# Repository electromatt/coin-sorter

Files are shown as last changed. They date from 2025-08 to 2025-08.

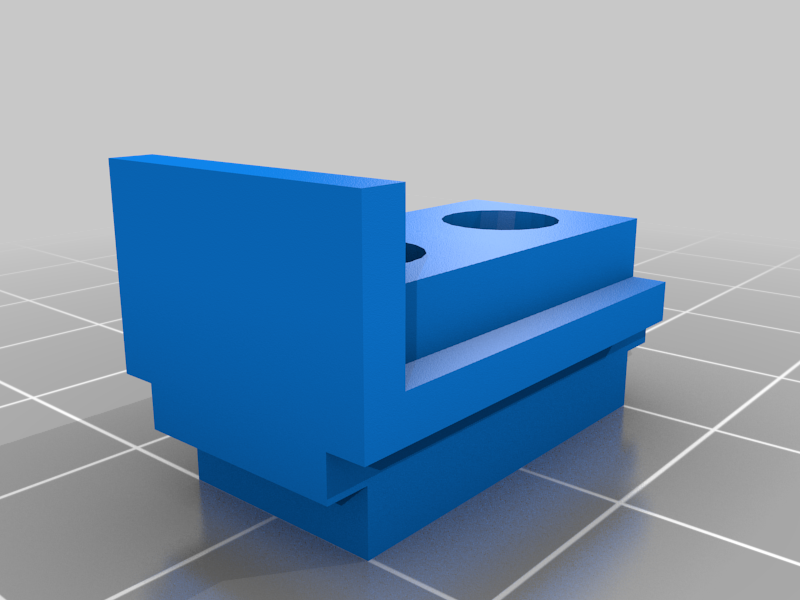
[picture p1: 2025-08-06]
models/images/Q-QuarterSensor.png

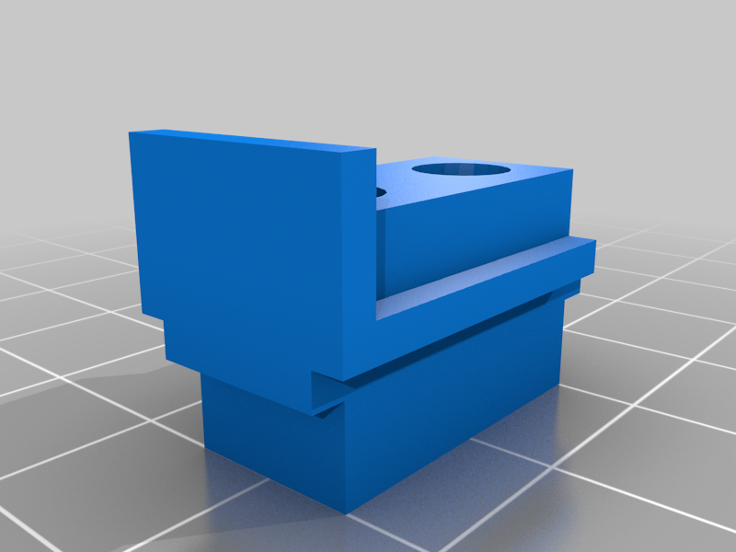
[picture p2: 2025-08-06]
models/images/T-NickelSensor.png

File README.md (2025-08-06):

# Coin Sorter with LED Matrix Display

A sophisticated coin sorting and counting system with real-time LED matrix display, motor control, and firework animations. This project automatically detects and counts US coins (pennies, nickels, dimes, quarters) while providing visual feedback through a 32x5 LED matrix display.

## Features

### 🪙 Coin Detection
- **4 Independent Sensors**: Separate analog sensors for each coin type
- **Real-time Detection**: Instant coin recognition with visual feedback
- **No Missed Coins**: Optimized detection algorithm ensures every coin is counted
- **Non-blocking Operation**: Coin detection never blocks other system functions

### 💰 Display System
- **32x5 LED Matrix**: High-resolution display showing dollar amounts
- **Money Format**: Displays totals in XX.XX format (e.g., $12.34)
- **Color-coded Feedback**: Different colors for different operations
- **Non-blocking Animations**: Firework celebrations for milestones

### ⚙️ Motor Control
- **Pulsing Operation**: Motor runs in controlled pulses for precise movement
- **Bidirectional Control**: Forward and backward sequences
- **Configurable Sequences**: Adjustable pulse timing and direction changes
- **H-bridge Control**: Full forward/backward control with PWM speed control

### 🎮 User Controls
- **Dollar Adjustment**: Add/subtract $1.00 with dedicated buttons
- **Motor Control**: Manual motor activation button
- **Reset Function**: Clear total amount (currently disabled to prevent blocking)
- **Debug Mode**: Comprehensive logging and sensor monitoring

### 💾 Data Persistence
- **EEPROM Storage**: Total amount persists across power cycles
- **Data Integrity**: Magic number verification ensures valid saved data
- **Automatic Loading**: System loads previous total on startup

## Hardware Requirements

### Core Components
- **Arduino Uno** (or compatible board)
- **32x5 LED Matrix** (160 NeoPixels)
- **4x Analog Sensors** (for coin detection)
- **DC Motor** with H-bridge driver
- **3x Push Buttons** (dollar add/subtract, motor control)

### Pin Configuration
```
LED Matrix: Pin 7
Penny Sensor: A2
Nickel Sensor: A1  
Dime Sensor: A3
Quarter Sensor: A0
Reset Button: Pin 6
Add Dollar: Pin 2
Subtract Dollar: Pin 3
Motor Forward: Pin 9
Motor Backward: Pin 10
Motor Button: Pin 8
Motor Enable: Pin 11 (PWM)
```

## Installation & Setup

### 1. Hardware Assembly
1. Connect the LED matrix to pin 7
2. Wire each coin sensor to its designated analog pin
3. Connect motor driver to pins 9, 10, 11 (H-bridge configuration)
4. Wire push buttons to their respective pins
5. Ensure proper power supply for motor and sensors

### 2. Software Setup
1. Install required libraries:
   ```bash
   # Arduino IDE Library Manager
   Adafruit NeoPixel
   ```
2. Upload `coin_sorter.ino` to your Arduino
3. Open Serial Monitor (9600 baud) for debug output

### 3. Configuration
Adjust these settings in the code as needed:
```cpp
#define DEBUG_MODE 1                    // Enable debug output
#define DEBOUNCE_DELAY 10              // Coin detection debounce (ms)
#define DISPLAY_DELAY 25               // Display update frequency (ms)
#define COIN_THRESHOLD 640             // Analog threshold for coin detection
#define FIREWORK_INTERVAL 1000         // Firework every $10.00 (1000 cents)
```

## Usage

### Basic Operation
1. **Power On**: System initializes and loads previous total from EEPROM
2. **Insert Coins**: Drop coins into the sorter - they're automatically detected and counted
3. **View Total**: Current total displays in real-time on LED matrix
4. **Celebrations**: Firework animations trigger at $10.00 milestones

### Button Functions
- **Add Dollar (+$1.00)**: Cyan flash, adds $1.00 to total
- **Subtract Dollar (-$1.00)**: Orange flash, subtracts $1.00 (prevents negative)
- **Motor Control**: Activates motor pulsing sequence
- **Reset**: Clears total (currently disabled to prevent blocking)

### Debug Features
When `DEBUG_MODE` is enabled:
- Real-time sensor value monitoring
- Coin detection logging with sensor values
- Motor operation status and sequence tracking
- EEPROM save/load confirmation

## Technical Details

### Coin Detection Algorithm
```cpp
// Threshold-based detection with debouncing
bool coinDetected = (analogValue <= COIN_THRESHOLD);

// Non-blocking state machine
if (coinDetected && !lastState && timeSinceLastDetection > debounceDelay) {
    // Register coin detection
    return coinValue;
}
```

### Motor Control System
- **Pulse Timing**: 100ms on, 100ms off
- **Sequence Pattern**: 4 forward pulses, 1 backward pulse per sequence
- **Total Sequences**: 2 complete sequences per activation
- **H-bridge Control**: Pin 9 (forward), Pin 10 (backward), Pin 11 (PWM enable)
- **Direction Logic**: Forward = Pin 9 HIGH, Pin 10 LOW; Backward = Pin 9 LOW, Pin 10 HIGH

### Display System
- **Resolution**: 32x5 pixels (160 total)
- **Format**: XX.XX dollar display
- **Colors**: Green (normal), Yellow (coin added), Red (error), Cyan (add dollar), Orange (subtract dollar)
- **Animation**: Non-blocking firework effects with multiple bursts

### Memory Management
- **EEPROM Storage**: Persistent total amount across power cycles
- **Magic Number**: Data integrity verification (0xAA55)
- **Automatic Loading**: System loads saved total on startup
- **Error Handling**: Graceful fallback to $0.00 if EEPROM data is invalid

## Code Organization

### Well-Documented Structure
The code includes comprehensive comments explaining:
- **Pin Functions**: What each pin controls and how
- **Configuration Values**: What each constant controls and units
- **Variable States**: Boolean logic and state machine explanations
- **Function Purpose**: What each function does and why
- **Complex Logic**: Motor control algorithms and animation systems

### Key Sections
```cpp
// Pin Definitions with clear explanations
#define MOTOR_FORWARD_PIN 9   // High to drive forward
#define MOTOR_BACKWARD_PIN 10 // High to drive backward
#define MOTOR_ENA_PIN 11      // PWM pin for motor speed control

// Configuration with units and purpose
#define DEBOUNCE_DELAY 10     // Milliseconds for button/coin debouncing
#define COIN_THRESHOLD 640    // Analog threshold for coin detection

// Variable explanations
bool motorDirection = true;    // true = forward, false = backward
bool pulseState = false;      // true = motor on, false = motor off
```

## Troubleshooting

### Common Issues

**Coins Not Detected:**
- Check sensor wiring and connections
- Verify analog pin assignments (A0-A3)
- Test sensor values in debug mode
- Adjust `COIN_THRESHOLD` if needed (default: 640)

**Motor Not Running:**
- Verify H-bridge connections (pins 9, 10, 11)
- Check power supply for motor
- Test motor pins with simple on/off code
- Ensure proper H-bridge configuration

**Display Issues:**
- Verify LED matrix connections to pin 7
- Check power supply for NeoPixels
- Test individual LED segments
- Verify 32x5 matrix configuration

**EEPROM Issues:**
- Check if total persists across power cycles
- Verify magic number in EEPROM
- Test EEPROM read/write functions
- Check for memory corruption

**False Coin Detections:**
- Check for electrical interference
- Adjust debounce timing (`DEBOUNCE_DELAY`)
- Verify sensor mounting and alignment
- Test individual sensor isolation

### Debug Commands
```cpp
// Enable comprehensive debug output
#define DEBUG_MODE 1

// Monitor sensor values in real-time
// Debug output shows: sensor index, analog value, coin value

// Motor operation tracking
// Debug shows: pulse count, sequence progress, direction changes
```

## Customization

### Adjusting Coin Detection
```cpp
// Modify detection threshold
#define COIN_THRESHOLD 640  // Adjust based on sensor calibration

// Change debounce timing
#define DEBOUNCE_DELAY 10   // Milliseconds
```

### Motor Configuration
```cpp
// Adjust pulse timing
#define PULSE_ON_TIME 100   // Milliseconds motor stays on
#define PULSE_OFF_TIME 100  // Milliseconds motor stays off

// Modify sequence pattern
#define FORWARD_PULSES 4    // Number of forward pulses per sequence
#define BACKWARD_PULSES 1   // Number of backward pulses per sequence
#define TOTAL_SEQUENCES 2   // Number of complete sequences to run
```

### Display Customization
```cpp
// Change LED brightness
strip.setBrightness(50);  // 0-255

// Modify firework frequency
#define FIREWORK_INTERVAL 1000  // Every $10.00 (1000 cents)
```

### EEPROM Configuration
```cpp
// Change EEPROM storage address
#define EEPROM_TOTAL_ADDRESS 0  // Address to store total amount

// Modify magic number for data validation
#define EEPROM_MAGIC_NUMBER 0xAA55  // Magic number to verify data is valid
```

## Safety & Maintenance

### Electrical Safety
- Use appropriate power supplies for motor and sensors
- Ensure proper grounding
- Add capacitors for motor noise suppression
- Use separate power for sensitive analog circuits

### Mechanical Maintenance
- Clean coin sensors regularly
- Lubricate motor components as needed
- Check for coin jams in sorting mechanism
- Inspect wiring connections periodically

### Software Updates
- Backup EEPROM data before updates
- Test new configurations thoroughly
- Monitor sensor values after changes
- Verify motor operation with new settings

## Recent Updates

### Code Improvements (Latest)
- **Restored Comprehensive Comments**: All pin functions, configuration values, and complex logic are now well-documented
- **EEPROM Loading on Startup**: System automatically loads previous total when powered on
- **Improved Code Organization**: Better structured with logical grouping of constants and variables
- **Enhanced Debug Output**: More detailed logging for troubleshooting
- **Non-blocking Operation**: All functions designed to prevent blocking coin detection

### Key Changes
- Added `loadTotalFromEEPROM()` call in `setup()` for automatic data restoration
- Restored detailed comments for all pin definitions and configuration values
- Improved variable documentation explaining state machines and boolean logic
- Enhanced motor control comments explaining H-bridge operation
- Better function documentation explaining purpose and behavior

## License

This project is open source. Feel free to modify and distribute according to your needs.

## Contributing

Contributions are welcome! Please:
1. Test thoroughly before submitting
2. Document any hardware changes
3. Include debug output for issues
4. Follow existing code style and comment standards

## Support

For issues or questions:
1. Check the troubleshooting section
2. Enable debug mode for detailed logging
3. Verify hardware connections
4. Test individual components
5. Check EEPROM data integrity

---

**Happy Coin Sorting! 🪙💰**

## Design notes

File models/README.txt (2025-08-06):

US Coin Sorter/Counter - Arduino by rleddington on Thingiverse: https://www.thingiverse.com/thing:5257512

Summary:
Fun coin sorting project for electronics enthusiasts.  This is a remix of "US Coin Sorter Variant" by pjm237, which was itself a remix of "COINSORTER" by neoprenox which I believe is for the Euro coins.  If you're only interested in the coin sorting functionality, I highly recommend pjm237's awesome project!  It works amazingly well.  This version is for US coins only and has been modified to fit a series of IR sensors, and Arduino UNO, and a 16x2 LCD Display to show the total value as well as the coin counts for each denomination.It requires an Arduino UNO and several electronics components and some skill with a soldering iron.  I'm working on a video which I'll link here on how to build and program it.  I also have several left-over components for the projects since amazon requires you to buy multiple of each component.  Let me know if you're interested in a 'kit' for the electronics parts minus the Arduino.Here are links to many of the part's you'll need to complete this project:On/Off Switchhttps://www.amazon.com/gp/product/B08R5PLDBP/ref=ppx_yo_dt_b_asin_title_o03_s00?ie=UTF8&amp;th=1Reset Buttonhttps://www.amazon.com/gp/product/B08JHSG717/ref=ppx_yo_dt_b_asin_title_o03_s00?ie=UTF8&amp;psc=1Battery Connector (9v)https://www.amazon.com/gp/product/B08SL9X2YC/ref=ppx_yo_dt_b_asin_title_o02_s00?ie=UTF8&amp;psc=1Perf Boardhttps://www.amazon.com/Prototyping-Circuit-Breadboards-Envistia-Mall/dp/B07RC68D5C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 Emitter Detectorhttps://www.amazon.com/dp/B07VK3PGR9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 Uno R3https://www.amazon.com/gp/product/B01EWOE0UU/ref=ppx_yo_dt_b_asin_title_o03_s00?ie=UTF8&amp;psc=1Jumper Wireshttps://www.amazon.com/Elegoo-EL-CP-004-Multicolored-Breadboard-arduino/dp/B01EV70C78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 Display Modulehttps://www.amazon.com/gp/product/B07S7PJYM6/ref=ppx_yo_dt_b_asin_title_o03_s02?ie=UTF8&amp;psc=1Wirewrap Wirehttps://www.amazon.com/gp/product/B01LWI20M0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 Bolts/Nuts &amp; Washershttps://www.amazon.com/gp/product/B08125LTBT/ref=ppx_yo_dt_b_search_asin_title?ie=UTF8&amp;psc=1

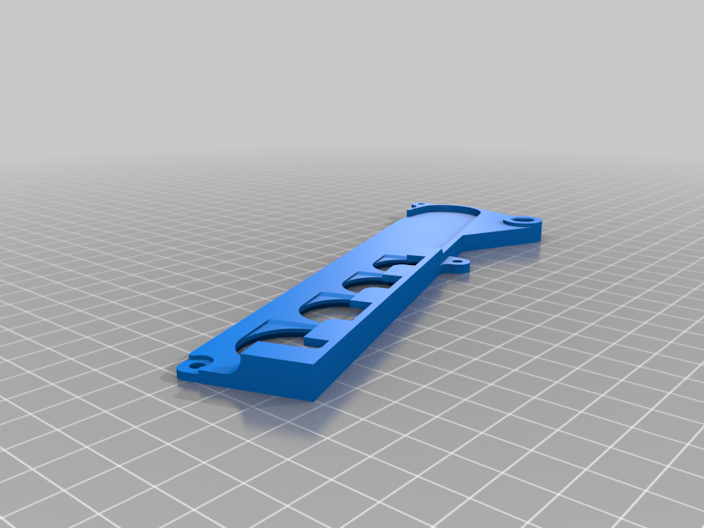
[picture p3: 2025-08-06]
models/images/B-Separator.png

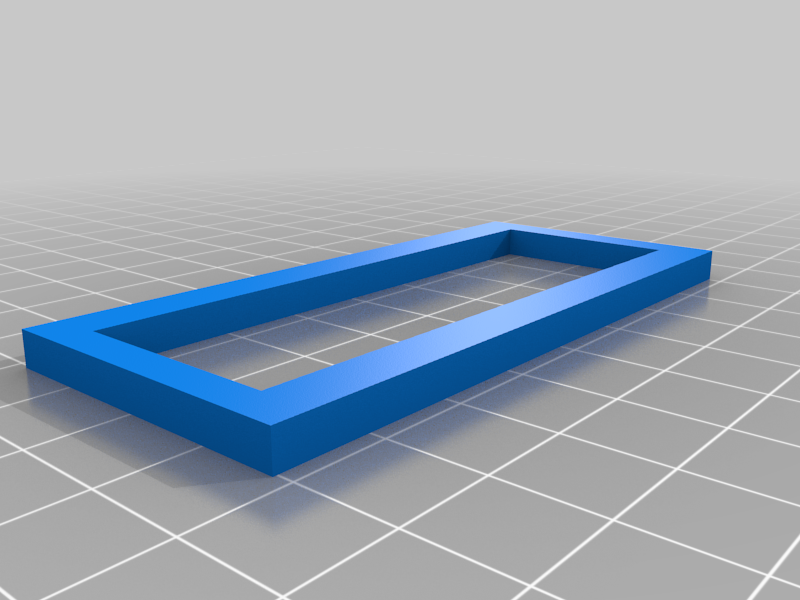
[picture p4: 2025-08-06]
models/images/O-FacePlate.png

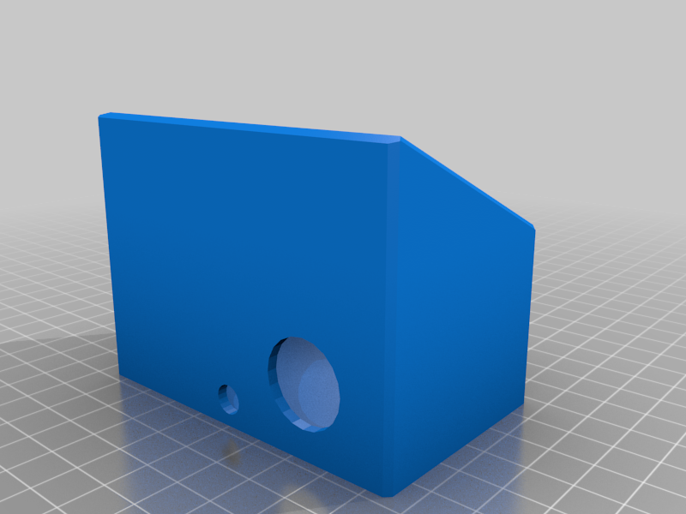
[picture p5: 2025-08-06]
models/images/N-DisplayCase.png

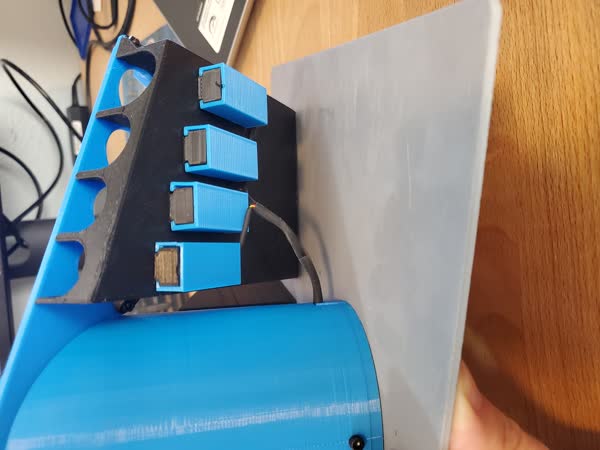
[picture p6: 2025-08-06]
models/images/f088567a-85c6-4a23-a1e6-7ee276b56d47.jpg

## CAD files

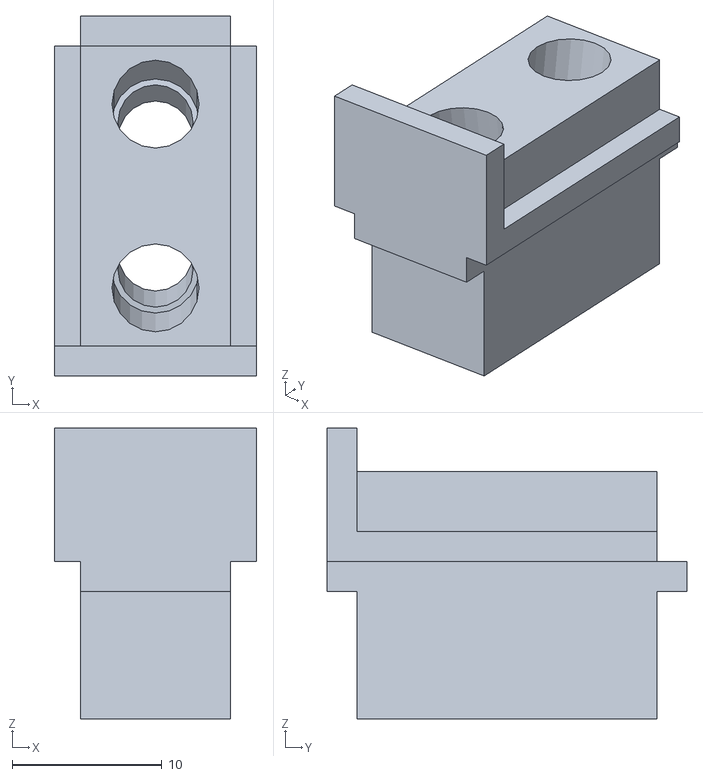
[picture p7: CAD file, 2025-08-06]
models/files/R-DimeSensor.stl
13.5 x 24.0 x 19.4

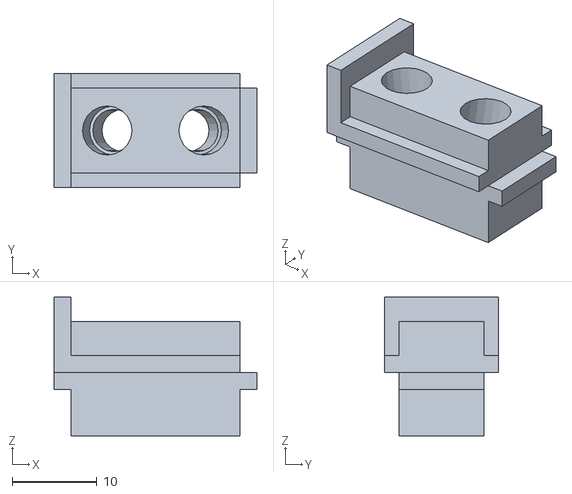
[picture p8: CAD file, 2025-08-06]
models/files/T-NickelSensor.stl
24.0 x 13.5 x 16.4

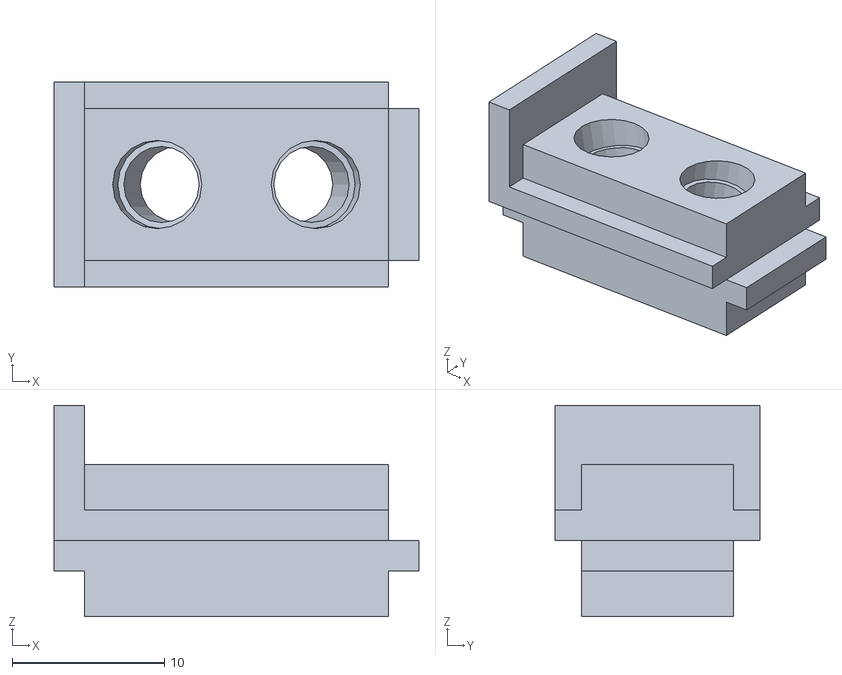
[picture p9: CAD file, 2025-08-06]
models/files/Q-QuarterSensor.stl
24.0 x 13.5 x 13.9

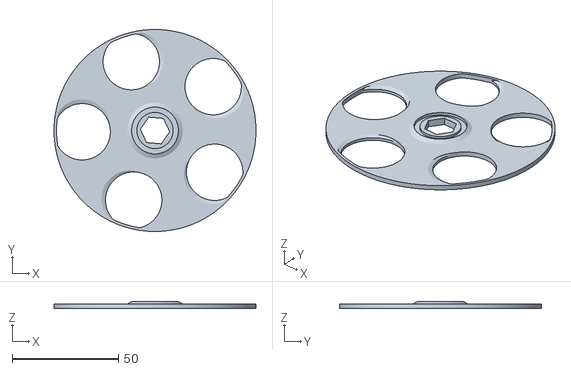
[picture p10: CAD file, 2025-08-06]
models/files/E-Rotor.stl
95.0 x 95.0 x 3.20

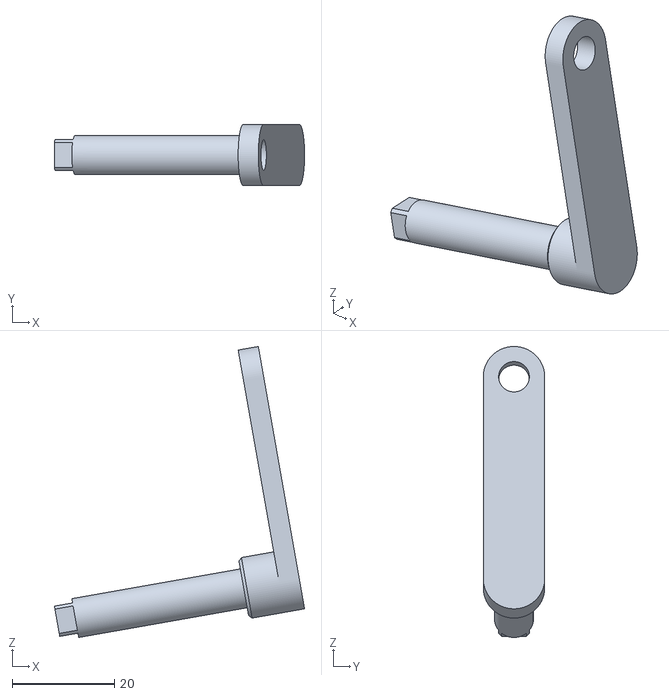
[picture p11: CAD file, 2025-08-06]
models/files/J-Crank.stl
48.8 x 12.0 x 56.8

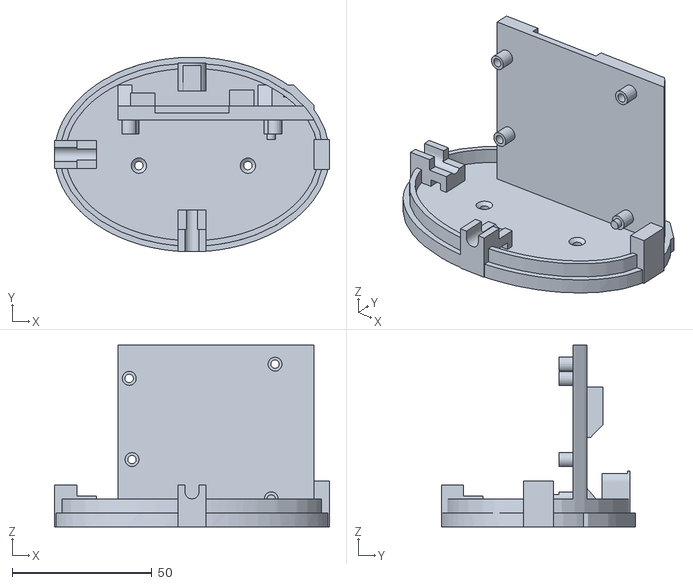
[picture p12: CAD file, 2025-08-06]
models/files/L-ArduinoBase.stl
98.4 x 69.6 x 65.0

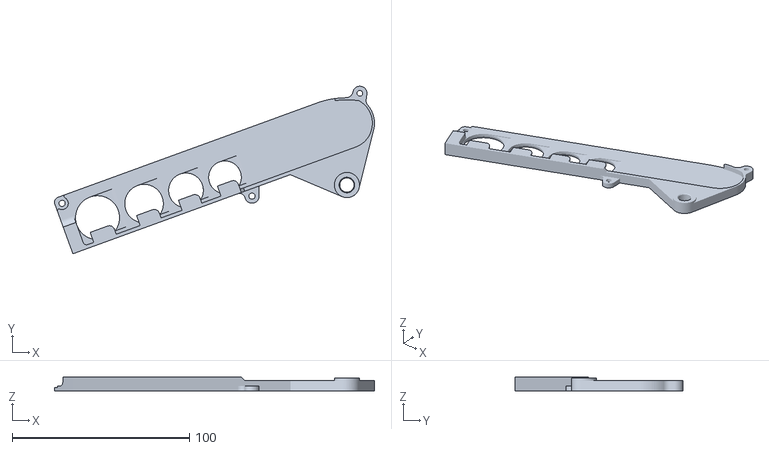
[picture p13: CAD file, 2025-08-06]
models/files/B-Separator.stl
180.4 x 94.4 x 8.00

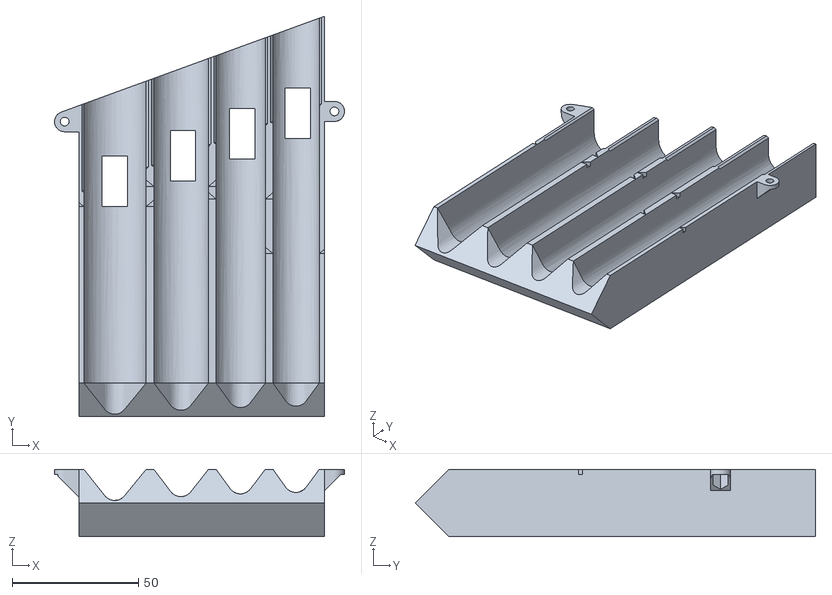
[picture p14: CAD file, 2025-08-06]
models/files/A-SlottedTray.stl
115.0 x 158.8 x 26.8

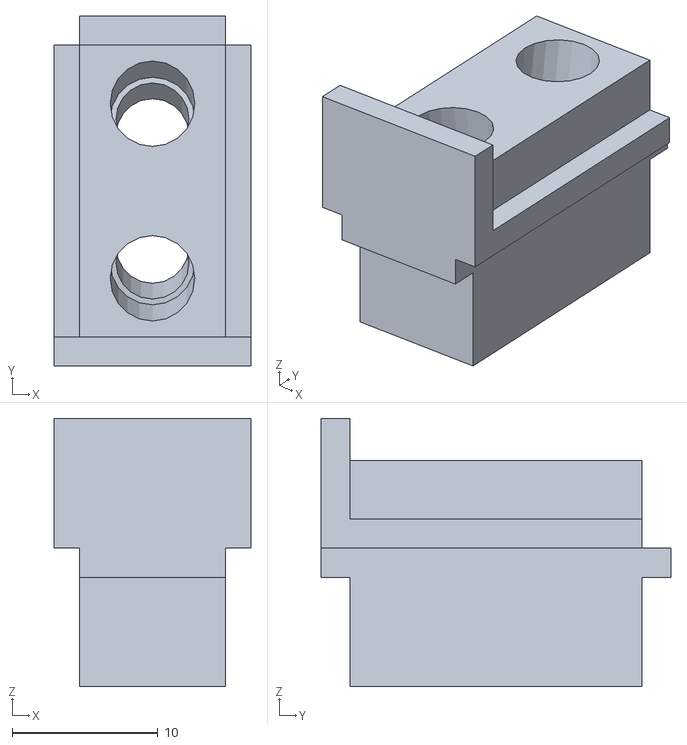
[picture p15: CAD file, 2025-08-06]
models/files/P-PennySensor.stl
13.5 x 24.0 x 18.4

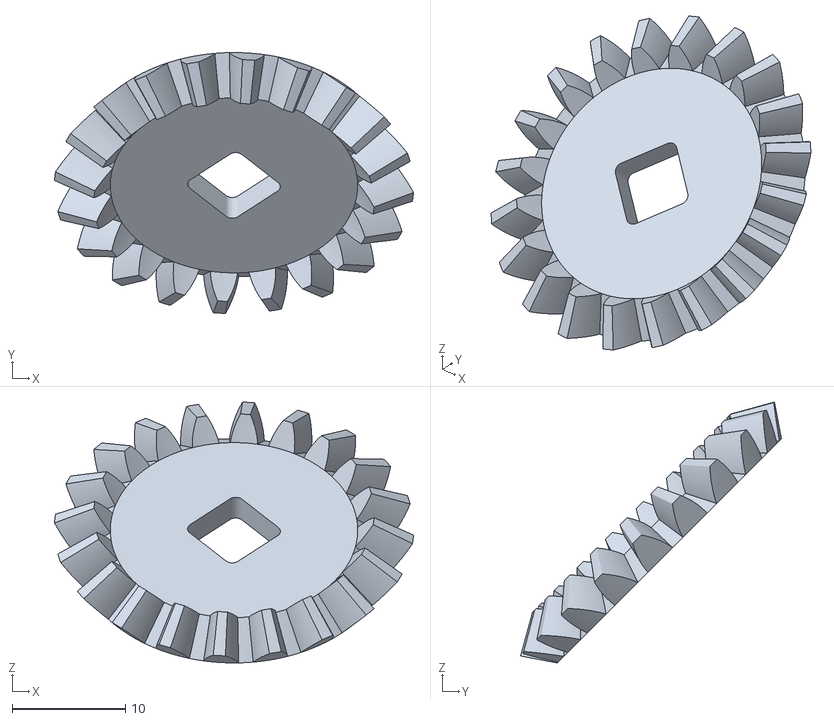
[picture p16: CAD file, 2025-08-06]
models/files/G-LargeGear.stl
31.7 x 23.0 x 23.0

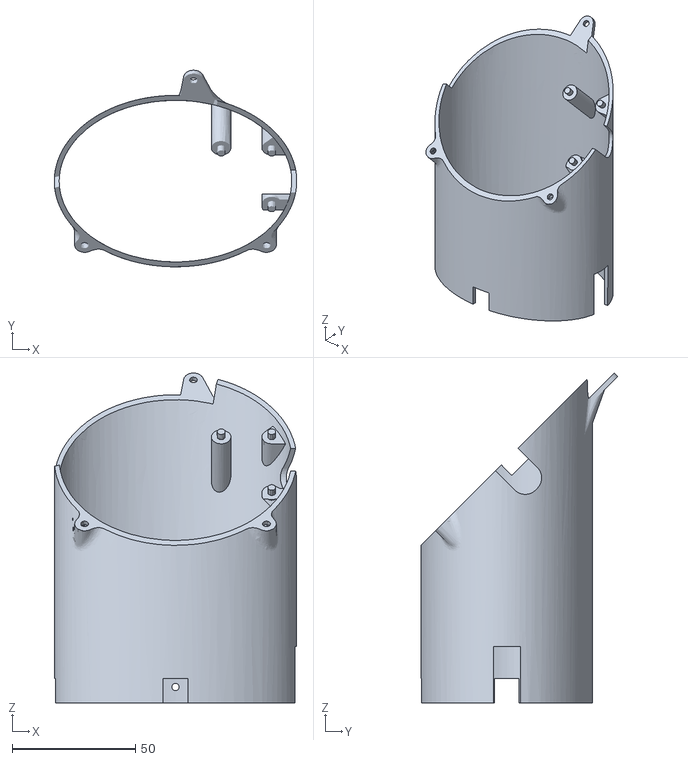
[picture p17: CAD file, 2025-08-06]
models/files/M-HopperStand.stl
98.4 x 79.8 x 133.9

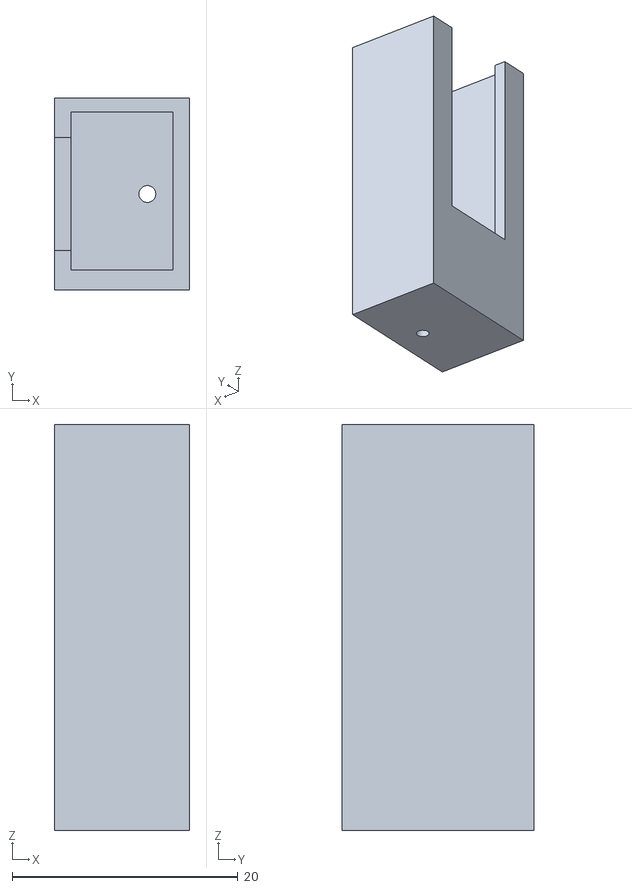
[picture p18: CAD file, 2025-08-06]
models/files/S-SensorCase.stl
12.0 x 17.0 x 36.0

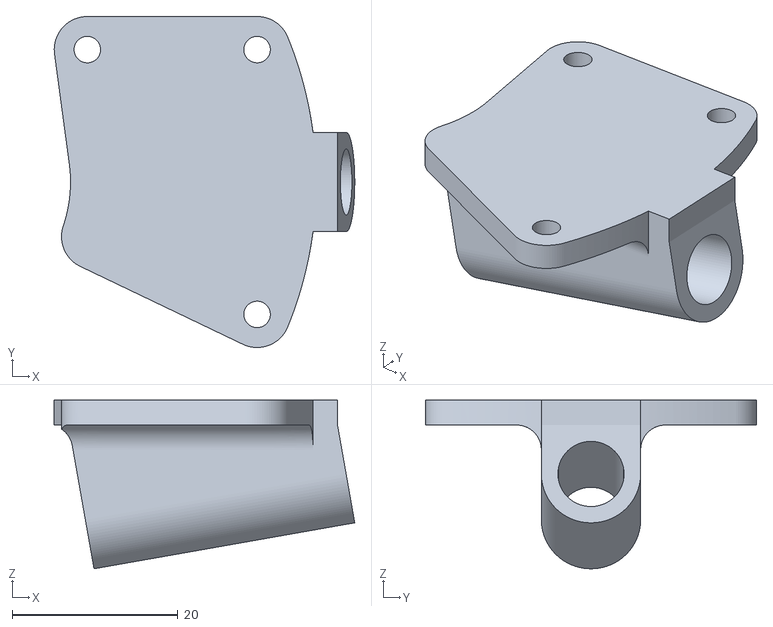
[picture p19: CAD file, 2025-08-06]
models/files/I-Crank_Mount.stl
36.3 x 40.0 x 20.4

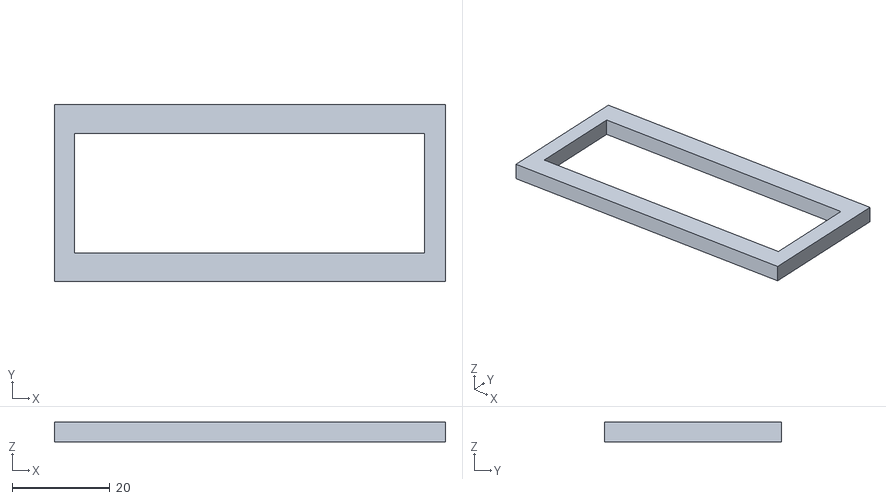
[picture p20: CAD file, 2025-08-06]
models/files/O-FacePlate.stl
80.1 x 36.2 x 4.00

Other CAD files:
models/files/N-DisplayCase.stl
models/files/K-Crank_Handle.stl
models/files/C-Hopper.stl
models/files/D-Rotor_Shaft.stl
models/files/F-Rotor_Tray.stl
models/files/H-SmallGear.stl

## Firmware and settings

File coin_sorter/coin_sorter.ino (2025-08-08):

/*
 * Coin Counter with LED Matrix Display
 * Displays running total in money format (xx.xx)
 * Uses 4 separate sensors for penny, nickel, dime, quarter
 */

#include <Adafruit_NeoPixel.h>
#include <EEPROM.h>
#ifdef __AVR__
  #include <avr/power.h>
#endif

// Pin Definitions
#define LED_PIN           7
#define QUARTER_SENSOR_PIN A0
#define NICKEL_SENSOR_PIN A1
#define PENNY_SENSOR_PIN  A2
#define DIME_SENSOR_PIN   A3
#define RESET_BUTTON_PIN  6
#define ADD_DOLLAR_PIN    2  // Button to add $1.00
#define SUBTRACT_DOLLAR_PIN 3  // Button to subtract $1.00
#define MOTOR_FORWARD_PIN 9   // High to drive forward
#define MOTOR_BACKWARD_PIN 10 // High to drive backward
#define MOTOR_BUTTON_PIN  8
#define MOTOR_ENA_PIN     11  // PWM pin for motor speed control

// LED Matrix Configuration
#define LED_COUNT         160  // 32x5 matrix
#define MATRIX_WIDTH      32
#define MATRIX_HEIGHT     5
#define DIGIT_WIDTH       3
#define DIGIT_HEIGHT      5
#define DIGIT_SPACING     1
#define DECIMAL_WIDTH     1

// Coin Values (in cents)
#define PENNY_VALUE       1
#define NICKEL_VALUE      5
#define DIME_VALUE        10
#define QUARTER_VALUE     25

// Configuration
#define DEBUG_MODE        1  // Set to 1 to enable debug features
#define MOTOR_DEBUG       0  // Set to 1 to enable motor-specific debug logs
#define FIREWORK_INTERVAL 1000  // Firework every $10.00 (1000 cents)
#define FIREWORK_FRAME_INTERVAL_MS 50
 // Delay between animation frames (higher = slower)
#define DEBOUNCE_DELAY    10  // Milliseconds for button/coin debouncing
#define DISPLAY_DELAY     25  // Milliseconds between display updates (legacy; not used for delay())
#define COIN_HYSTERESIS   70  // Hysteresis to avoid chatter around threshold
#define COIN_MARGIN       80  // Margin above baseline to detect a coin
#define DISPLAY_REFRESH_MS 100 // How often to refresh steady display when idle
// Autosave configuration
#define SAVE_INACTIVITY_MS 1000 // Save to EEPROM after this much inactivity

// Motor Configuration
#define PULSE_ON_TIME     40  // Milliseconds motor stays on
#define PULSE_OFF_TIME    50  // Milliseconds motor stays off
#define FORWARD_PULSES    5    // Number of forward pulses per sequence
#define BACKWARD_PULSES   2    // Number of backward pulses per sequence
#define TOTAL_SEQUENCES   20    // Number of complete sequences to run
// Motor PWM speed (0-255). Lower values slow the motor to help coins settle
#define MOTOR_SPEED_FORWARD 255
#define MOTOR_SPEED_BACKWARD 160

// EEPROM Configuration
#define EEPROM_TOTAL_ADDRESS 0  // Address to store total amount
#define EEPROM_MAGIC_NUMBER  0xAA55  // Magic number to verify data is valid

// Global Variables
long totalAmount = 21000;
unsigned long lastSensorTimes[4] = {0, 0, 0, 0};
bool lastSensorStates[4] = {false, false, false, false}; // false = no coin detected
long lastFireworkMilestone = 0;

// Animation state variables
bool animationPlaying = false;
unsigned long animationStartTime = 0;
unsigned long lastAnimationFrameMs = 0;
int animationStep = 0;
int fireworkBurst = 0;
int fireworkCenterX = 0;
int fireworkCenterY = 0;
uint32_t fireworkColor = 0;
int flashStep = 0;

// Motor control variables
bool motorRunning = false;
bool motorDirection = true; // true = forward, false = backward
unsigned long motorStartTime = 0;
bool lastMotorButtonState = HIGH;
unsigned long lastMotorButtonTime = 0;
unsigned long lastPulseTime = 0;
bool pulseState = false; // true = motor on, false = motor off
int pulseCount = 0;
int sequenceCount = 0; // Which sequence we're in (0 = first, 1 = second, etc.)
int pulsesInCurrentSequence = 0; // Pulses completed in current sequence
// Autosave state
bool hasUnsavedTotalChanges = false;
unsigned long lastTotalChangeMs = 0;

// Display state
long lastDisplayedAmount = -1;
unsigned long lastDisplayUpdate = 0;

// Button variables
bool lastAddButtonState = HIGH;
bool lastSubtractButtonState = HIGH;
unsigned long lastAddButtonTime = 0;
unsigned long lastSubtractButtonTime = 0;

// NeoPixel strip object
Adafruit_NeoPixel strip(LED_COUNT, LED_PIN, NEO_GRB + NEO_KHZ800);

// Digit patterns for 0-9 (3x5 grid)
const bool DIGIT_PATTERNS[10][5][3] = {
  {{1,1,1}, {1,0,1}, {1,0,1}, {1,0,1}, {1,1,1}}, // 0
  {{0,1,0}, {1,1,0}, {0,1,0}, {0,1,0}, {1,1,1}}, // 1
  {{1,1,1}, {0,0,1}, {1,1,1}, {1,0,0}, {1,1,1}}, // 2
  {{1,1,1}, {0,0,1}, {1,1,1}, {0,0,1}, {1,1,1}}, // 3
  {{1,0,1}, {1,0,1}, {1,1,1}, {0,0,1}, {0,0,1}}, // 4
  {{1,1,1}, {1,0,0}, {1,1,1}, {0,0,1}, {1,1,1}}, // 5
  {{1,1,1}, {1,0,0}, {1,1,1}, {1,0,1}, {1,1,1}}, // 6
  {{1,1,1}, {0,0,1}, {0,0,1}, {0,0,1}, {0,0,1}}, // 7
  {{1,1,1}, {1,0,1}, {1,1,1}, {1,0,1}, {1,1,1}}, // 8
  {{1,1,1}, {1,0,1}, {1,1,1}, {0,0,1}, {1,1,1}}  // 9
};

// Decimal point pattern
const bool DECIMAL_PATTERN[5][1] = {{0}, {0}, {0}, {0}, {1}};

// Sensor configuration
// Order is {PENNY(A2), NICKEL(A1), DIME(A3), QUARTER(A0)}
const int SENSOR_PINS[4] = {PENNY_SENSOR_PIN, NICKEL_SENSOR_PIN, DIME_SENSOR_PIN, QUARTER_SENSOR_PIN};
const int COIN_VALUES[4] = {PENNY_VALUE, NICKEL_VALUE, DIME_VALUE, QUARTER_VALUE};
// Baselines captured by user for A0..A3 were {760, 570, 650, 690} (untriggered)
// Remapped to our sensor order (PENNY=A2, NICKEL=A1, DIME=A3, QUARTER=A0):
const int SENSOR_BASELINES[4] = {650, 570, 690, 760};

// Helper to read a more stable analog value
int readAnalogAveraged(int pin, int samples = 5) {
  long sum = 0;
  for (int s = 0; s < samples; s++) {
    sum += analogRead(pin);
  }
  return (int)(sum / samples);
}

void setup() {
  #if defined(__AVR_ATtiny85__) && (F_CPU == 16000000)
    clock_prescale_set(clock_div_1);
  #endif

  // Initialize pins
  for (int i = 0; i < 4; i++) {
    pinMode(SENSOR_PINS[i], INPUT); // Analog pins don't need pullup
  }
  pinMode(RESET_BUTTON_PIN, INPUT_PULLUP);
  pinMode(MOTOR_BUTTON_PIN, INPUT_PULLUP);
  pinMode(ADD_DOLLAR_PIN, INPUT_PULLUP);
  pinMode(SUBTRACT_DOLLAR_PIN, INPUT_PULLUP);
  
  // Initialize motor pins
  pinMode(MOTOR_FORWARD_PIN, OUTPUT);
  pinMode(MOTOR_BACKWARD_PIN, OUTPUT);
  pinMode(MOTOR_ENA_PIN, OUTPUT);
  digitalWrite(MOTOR_FORWARD_PIN, LOW);
  digitalWrite(MOTOR_BACKWARD_PIN, LOW);
  analogWrite(MOTOR_ENA_PIN, 0); // Ensure stopped at boot
  
  // Test motor briefly on startup
  // digitalWrite(MOTOR_FORWARD_PIN, HIGH);
  // delay(100);
  // digitalWrite(MOTOR_FORWARD_PIN, LOW);
  
  #if DEBUG_MODE
    // Initialize Serial for debug output
    Serial.begin(9600);
    Serial.println("Coin Sorter Debug Mode Enabled");
  #endif

  // Initialize LED matrix
  strip.begin();
  strip.show();
  strip.setBrightness(50);

  // Load saved total from EEPROM
  loadTotalFromEEPROM();
  
  // Initialize sensor states to prevent false triggers on startup
  for (int i = 0; i < 4; i++) {
    int currentValue = readAnalogAveraged(SENSOR_PINS[i]);
    int thresholdHigh = SENSOR_BASELINES[i] + COIN_MARGIN;
    lastSensorStates[i] = (currentValue >= thresholdHigh); // coin triggers higher value
    lastSensorTimes[i] = millis();
    #if DEBUG_MODE
      Serial.print("Sensor ");
      Serial.print(i);
      Serial.print(" initial value: ");
      Serial.print(currentValue);
      Serial.print(" (high thr: ");
      Serial.print(thresholdHigh);
      Serial.print(", state: ");
      Serial.print(lastSensorStates[i] ? "coin detected" : "no coin");
      Serial.println(")");
    #endif
  }
  
  // Display initial amount
  updateDisplay(totalAmount, strip.Color(0, 255, 0));
  
  #if DEBUG_MODE
    Serial.print("Initial total: $");
    Serial.println(totalAmount / 100.0, 2);
  #endif
}

void loop() {
  // Check for coin detection (highest priority)
  int coinValue = detectCoin();
  if (coinValue > 0) {
    addCoin(coinValue);
  }

  // Check dollar adjustment buttons
  checkDollarButtons();

  // Check motor button
  checkMotorButton();

  // Check if delayed save is due
  if (hasUnsavedTotalChanges && !motorRunning && (millis() - lastTotalChangeMs) >= SAVE_INACTIVITY_MS) {
    saveTotalToEEPROM();
    hasUnsavedTotalChanges = false;
    #if DEBUG_MODE
      Serial.println("Autosave to EEPROM completed");
    #endif
  }

  // Handle animation or normal display
  if (animationPlaying) {
    updateAnimation();
  } else {
    unsigned long now = millis();
    // Only refresh the display when amount changed or periodic refresh
    if (totalAmount != lastDisplayedAmount || (now - lastDisplayUpdate) >= DISPLAY_REFRESH_MS) {
      updateDisplay(totalAmount, strip.Color(0, 255, 0));
      lastDisplayedAmount = totalAmount;
      lastDisplayUpdate = now;
    }
  }
  // No blocking delay; keep loop fast to avoid missing short sensor events
}

// Detect which coin was inserted
int detectCoin() {
  unsigned long currentTime = millis();
  
  for (int i = 0; i < 4; i++) {
    int currentValue = readAnalogAveraged(SENSOR_PINS[i]);
    int thresholdHigh = SENSOR_BASELINES[i] + COIN_MARGIN;
    int thresholdLow  = thresholdHigh - COIN_HYSTERESIS;
    bool coinDetected = (currentValue >= thresholdHigh);
    bool coinReleased = (currentValue <= thresholdLow);
    
    if (coinDetected && !lastSensorStates[i] && 
        (currentTime - lastSensorTimes[i]) > DEBOUNCE_DELAY) {
      lastSensorTimes[i] = currentTime;
      lastSensorStates[i] = true;
      #if DEBUG_MODE
        Serial.print("Coin detected on sensor ");
        Serial.print(i);
        Serial.print(" (Value: ");
        Serial.print(currentValue);
        Serial.print(", thrH: ");
        Serial.print(thresholdHigh);
        Serial.print(") - Coin value: ");
        Serial.println(COIN_VALUES[i]);
      #endif
      return COIN_VALUES[i];
    }
    
    if (coinReleased && lastSensorStates[i]) {
      lastSensorStates[i] = false;
    }
  }
  
  return 0;
}

// Add coin to total with visual feedback
void addCoin(int value) {
  long previousAmount = totalAmount;
  totalAmount += value;
  hasUnsavedTotalChanges = true;
  lastTotalChangeMs = millis();
  
  // Flash display (brief) - non-blocking
  updateDisplay(totalAmount, strip.Color(255, 255, 0));
    
  // Check if we reached a new firework milestone
  long currentMilestone = totalAmount / FIREWORK_INTERVAL;
  long previousMilestone = previousAmount / FIREWORK_INTERVAL;
  
  if (currentMilestone > previousMilestone) {
    startFireworkAnimation();
  }
}

// Update the LED matrix display
void updateDisplay(long amount, uint32_t color) {
  strip.clear();
  drawMoney(amount, color);
  strip.show();
}

// Draw money amount in xx.xx format
void drawMoney(long amount, uint32_t color) {
  long dollars = amount / 100;
  long cents = amount % 100;
  
  String dollarStr = String(dollars);
  String centStr = (cents < 10) ? "0" + String(cents) : String(cents);
  
  // Calculate display width and position
  int maxDollarDigits = (MATRIX_WIDTH - 10) / 4;
  if (dollarStr.length() > maxDollarDigits) {
    dollarStr = dollarStr.substring(dollarStr.length() - maxDollarDigits);
  }
  
  int totalWidth = (dollarStr.length() * 4) + 2 + 8;
  int startX = MATRIX_WIDTH - totalWidth;
  
  // Draw dollars
  int currentX = startX;
  for (int i = 0; i < dollarStr.length(); i++) {
    drawDigit(dollarStr.charAt(i) - '0', currentX, 0, color);
    currentX += DIGIT_WIDTH + DIGIT_SPACING;
  }
  
  // Draw decimal point
  drawDecimalPoint(currentX, 0, color);
  currentX += DECIMAL_WIDTH + DIGIT_SPACING;
  
  // Draw cents
  for (int i = 0; i < centStr.length(); i++) {
    drawDigit(centStr.charAt(i) - '0', currentX, 0, color);
    currentX += DIGIT_WIDTH + DIGIT_SPACING;
  }
}

// Draw a single digit
void drawDigit(int digit, int startX, int startY, uint32_t color) {
  if (digit < 0 || digit > 9) return;
  
  for (int y = 0; y < DIGIT_HEIGHT; y++) {
    for (int x = 0; x < DIGIT_WIDTH; x++) {
      if (DIGIT_PATTERNS[digit][y][x]) {
        setMatrixPixel(startX + x, startY + y, color);
      }
    }
  }
}

// Draw decimal point
void drawDecimalPoint(int startX, int startY, uint32_t color) {
  for (int y = 0; y < DIGIT_HEIGHT; y++) {
    if (DECIMAL_PATTERN[y][0]) {
      setMatrixPixel(startX, startY + y, color);
    }
  }
}

// Set pixel color on the LED matrix
void setMatrixPixel(int x, int y, uint32_t color) {
  if (x < 0 || x >= MATRIX_WIDTH || y < 0 || y >= MATRIX_HEIGHT) return;
  
  int flippedY = MATRIX_HEIGHT - 1 - y;
  int flippedX = MATRIX_WIDTH - 1 - x;
  
  int pixelIndex;
  if (flippedY % 2 == 0) {
    pixelIndex = flippedY * MATRIX_WIDTH + flippedX;
  } else {
    pixelIndex = flippedY * MATRIX_WIDTH + (MATRIX_WIDTH - 1 - flippedX);
  }
  
  strip.setPixelColor(pixelIndex, color);
}

// Firework animation functions
void startFireworkAnimation() {
  animationPlaying = true;
  animationStartTime = millis();
  lastAnimationFrameMs = animationStartTime;
  animationStep = 0;
  fireworkBurst = 0;
  flashStep = 0;
  
  // Initialize first firework
  fireworkCenterX = random(8, MATRIX_WIDTH - 8);
  fireworkCenterY = random(1, MATRIX_HEIGHT - 1);
  uint32_t colors[] = {strip.Color(255, 0, 0), strip.Color(0, 255, 0), 
                       strip.Color(0, 0, 255), strip.Color(255, 255, 0),
                       strip.Color(255, 0, 255), strip.Color(0, 255, 255)};
  fireworkColor = colors[random(6)];
}

void updateAnimation() {
  unsigned long now = millis();
  if ((now - lastAnimationFrameMs) < FIREWORK_FRAME_INTERVAL_MS) {
    return; // not time for next frame yet
  }
  lastAnimationFrameMs = now;
  // Handle different animation phases
  if (fireworkBurst < 3) {
    // Firework burst phase
    if (animationStep < 8) {
      // Expanding circle
      strip.clear();
      for (int angle = 0; angle < 360; angle += 10) {
        int x = fireworkCenterX + animationStep * cos(angle * PI / 180);
        int y = fireworkCenterY + animationStep * sin(angle * PI / 180);
        
        if (x >= 0 && x < MATRIX_WIDTH && y >= 0 && y < MATRIX_HEIGHT) {
          setMatrixPixel(x, y, fireworkColor);
        }
      }
      strip.show();
      animationStep++;
    } else {
      // Move to next burst or sparkle phase
      fireworkBurst++;
      if (fireworkBurst < 3) {
        // Start next firework
        fireworkCenterX = random(8, MATRIX_WIDTH - 8);
        fireworkCenterY = random(1, MATRIX_HEIGHT - 1);
        uint32_t colors[] = {strip.Color(255, 0, 0), strip.Color(0, 255, 0), 
                             strip.Color(0, 0, 255), strip.Color(255, 255, 0),
                             strip.Color(255, 0, 255), strip.Color(0, 255, 255)};
        fireworkColor = colors[random(6)];
        animationStep = 0;
      }
    }
  } else if (flashStep < 6) {
    // Final celebration flash
    if (flashStep % 2 == 0) {
      strip.fill(strip.Color(255, 255, 255));
    } else {
      strip.clear();
    }
    strip.show();
    flashStep++;
  } else {
    // Animation complete
    animationPlaying = false;
    strip.clear();
    strip.show();
  }
}

// Motor control functions
void checkMotorButton() {
  bool currentButtonState = digitalRead(MOTOR_BUTTON_PIN);
  unsigned long currentTime = millis();
  
  // Check for button press with debouncing
  if (currentButtonState == LOW && lastMotorButtonState == HIGH && 
      (currentTime - lastMotorButtonTime) > DEBOUNCE_DELAY) {
    
    if (!motorRunning) {
      startMotor();
      lastMotorButtonTime = currentTime;
      #if MOTOR_DEBUG
        // Debug: Flash display to show button was detected
        updateDisplay(totalAmount, strip.Color(255, 0, 255)); // Purple flash
        Serial.println("Motor button pressed");
      #endif
    }
  }
  
  // Handle motor pulsing if running
  if (motorRunning) {
    updateMotorPulse(currentTime);
  }
  
  lastMotorButtonState = currentButtonState;
}

void startMotor() {
  motorRunning = true;
  motorStartTime = millis();
  lastPulseTime = millis();
  pulseState = true; // Start with motor on
  pulseCount = 0; // Reset pulse counter
  sequenceCount = 0; // Reset sequence counter
  pulsesInCurrentSequence = 0; // Reset sequence pulse counter
  
  // Always start with forward direction
  motorDirection = true;
  
  // Set direction pins for forward
  digitalWrite(MOTOR_FORWARD_PIN, HIGH);
  digitalWrite(MOTOR_BACKWARD_PIN, LOW);
  analogWrite(MOTOR_ENA_PIN, MOTOR_SPEED_FORWARD);
  
  #if MOTOR_DEBUG
    Serial.print("Motor: Starting ");
    Serial.print(TOTAL_SEQUENCES);
    Serial.print(" sequences (");
    Serial.print(FORWARD_PULSES);
    Serial.print(" forward, ");
    Serial.print(BACKWARD_PULSES);
    Serial.println(" backward each)");
  #endif
}

void stopMotor() {
  motorRunning = false;
  digitalWrite(MOTOR_FORWARD_PIN, LOW);
  digitalWrite(MOTOR_BACKWARD_PIN, LOW);
  analogWrite(MOTOR_ENA_PIN, 0);
  pulseState = false;
  pulseCount = 0;
  sequenceCount = 0;
  pulsesInCurrentSequence = 0;
  // No immediate save; autosave in loop after inactivity
  #if MOTOR_DEBUG
    Serial.println("Motor stopped - autosave pending");
  #endif
}

void updateMotorPulse(unsigned long currentTime) {
  if (pulseState) {
    // Motor is currently on, check if it should turn off
    if ((currentTime - lastPulseTime) >= PULSE_ON_TIME) {
      // Turn motor OFF by setting both pins LOW and ENA PWM to 0
      digitalWrite(MOTOR_FORWARD_PIN, LOW);
      digitalWrite(MOTOR_BACKWARD_PIN, LOW);
      analogWrite(MOTOR_ENA_PIN, 0);
      pulseState = false;
      lastPulseTime = currentTime;
      
      #if MOTOR_DEBUG
        Serial.println("Motor: OFF");
      #endif
    }
  } else {
    // Motor is currently off, check if it should turn on
    if ((currentTime - lastPulseTime) >= PULSE_OFF_TIME) {
      pulseCount++; // Increment total pulse counter
      pulsesInCurrentSequence++; // Increment sequence pulse counter
      
      // Check if we need to change direction within current sequence
      if (pulsesInCurrentSequence >= FORWARD_PULSES && motorDirection) {
        // Switch to backward direction
        motorDirection = false;
        #if MOTOR_DEBUG
          Serial.println("Motor: Switching to BACKWARD");
        #endif
      }
      
      // Check if current sequence is complete
      if (pulsesInCurrentSequence >= (FORWARD_PULSES + BACKWARD_PULSES)) {
        sequenceCount++;
        pulsesInCurrentSequence = 0;
        motorDirection = true; // Reset to forward for next sequence
        
        #if MOTOR_DEBUG
          Serial.print("Motor: Completed sequence ");
          Serial.print(sequenceCount);
          Serial.print("/");
          Serial.println(TOTAL_SEQUENCES);
        #endif
        
        // Check if all sequences are complete
        if (sequenceCount >= TOTAL_SEQUENCES) {
          stopMotor();
          return;
        }
      }
      
      // Turn motor ON in current direction
      if (motorDirection) {
        // Forward: Pin 9 HIGH, Pin 10 LOW, set PWM speed
        digitalWrite(MOTOR_FORWARD_PIN, HIGH);
        digitalWrite(MOTOR_BACKWARD_PIN, LOW);
        analogWrite(MOTOR_ENA_PIN, MOTOR_SPEED_FORWARD);
      } else {
        // Backward: Pin 9 LOW, Pin 10 HIGH, set PWM speed
        digitalWrite(MOTOR_FORWARD_PIN, LOW);
        digitalWrite(MOTOR_BACKWARD_PIN, HIGH);
        analogWrite(MOTOR_ENA_PIN, MOTOR_SPEED_BACKWARD);
      }
      
      pulseState = true;
      lastPulseTime = currentTime;
      
      #if MOTOR_DEBUG
        Serial.print("Motor: ON (Pulse ");
        Serial.print(pulseCount);
        Serial.print(", Sequence ");
        Serial.print(sequenceCount + 1);
        Serial.print("/");
        Serial.print(TOTAL_SEQUENCES);
        Serial.print(", Sequence Pulse ");
        Serial.print(pulsesInCurrentSequence);
        Serial.print("/");
        Serial.print(FORWARD_PULSES + BACKWARD_PULSES);
        Serial.print(" - ");
        Serial.print(motorDirection ? "FORWARD" : "BACKWARD");
        Serial.println(")");
      #endif
    }
  }
}

// Dollar adjustment button functions
void checkDollarButtons() {
  unsigned long currentTime = millis();
  
  // Check add dollar button
  bool currentAddState = digitalRead(ADD_DOLLAR_PIN);
  if (currentAddState == LOW && lastAddButtonState == HIGH && 
      (currentTime - lastAddButtonTime) > DEBOUNCE_DELAY) {
    addDollar();
    lastAddButtonTime = currentTime;
  }
  lastAddButtonState = currentAddState;
  
  // Check subtract dollar button
  bool currentSubtractState = digitalRead(SUBTRACT_DOLLAR_PIN);
  if (currentSubtractState == LOW && lastSubtractButtonState == HIGH && 
      (currentTime - lastSubtractButtonTime) > DEBOUNCE_DELAY) {
    subtractDollar();
    lastSubtractButtonTime = currentTime;
  }
  lastSubtractButtonState = currentSubtractState;
}

void addDollar() {
  long previousAmount = totalAmount;
  totalAmount += 100; // Add $1.00 (100 cents)
  hasUnsavedTotalChanges = true;
  lastTotalChangeMs = millis();
  
  #if DEBUG_MODE
    Serial.print("Added $1.00 - New total: $");
    Serial.println(totalAmount / 100.0, 2);
  #endif
  
  // Flash display to show adjustment - non-blocking
  updateDisplay(totalAmount, strip.Color(0, 255, 255)); // Cyan flash
     
  // Check if we reached a new firework milestone
  long currentMilestone = totalAmount / FIREWORK_INTERVAL;
  long previousMilestone = previousAmount / FIREWORK_INTERVAL;
  
  if (currentMilestone > previousMilestone) {
    startFireworkAnimation();
  }
}

void subtractDollar() {
  if (totalAmount >= 100) { // Prevent negative amounts
    totalAmount -= 100; // Subtract $1.00 (100 cents)
    hasUnsavedTotalChanges = true;
    lastTotalChangeMs = millis();
    
    #if DEBUG_MODE
      Serial.print("Subtracted $1.00 - New total: $");
      Serial.println(totalAmount / 100.0, 2);
    #endif
    
    // Flash display to show adjustment - non-blocking
    updateDisplay(totalAmount, strip.Color(255, 165, 0)); // Orange flash
  } else {
    #if DEBUG_MODE
      Serial.println("Cannot subtract $1.00 - total would be negative");
    #endif
    // Flash red to indicate error - non-blocking
    updateDisplay(totalAmount, strip.Color(255, 0, 0)); // Red flash
  }
}
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

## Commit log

2025-08-06 Initial commit: Coin Sorter with LED Matrix Display
    - Arduino code for coin detection and counting
    - 32x5 LED matrix display with firework animations
    - Motor control with pulsing sequences
    - 3D models for complete coin sorter assembly
    - Comprehensive documentation and README
    - Debug features and sensor monitoring
    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
    [A-SlottedTray.stl, B-Separator.stl, C-Hopper.stl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]
2025-08-06 Restore comprehensive comments and add EEPROM loading on startup - Restored detailed comments for all pin functions, configuration values, and complex logic - Added loadTotalFromEEPROM() call in setu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
2025-08-07 Improve reliability and efficiency:\n- Initialize sensor states on startup to prevent false triggers\n- Add hysteresis to coin detection to avoid chatter\n- Make main loop non-blocking; throttle disp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
    [coin_sorter.ino]
2025-08-07 Add MOTOR_DEBUG flag and scope motor logs under it; keep general logs under DEBUG_MODE.\n\nModel used: GPT-5
2025-08-07 Per-sensor coin detection using baselines and rising-edge logic:\n- Add SENSOR_BASELINES and COIN_MARGIN, use averaged reads\n- Trigger when value rises above baseline+margin with hysteresis\n- Initi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
2025-08-07 Unify EEPROM autosave in main loop:\n- Add SAVE_INACTIVITY_MS and autosave state\n- Mark changes in addCoin/addDollar/subtractDollar\n- Remove delayed save logic from motor\n- Save after inactivity w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
2025-08-08 Add FIREWORK_FRAME_INTERVAL_MS to control animation speed and gate frames by time.\n\nModel used: GPT-5
2025-08-08 Adjust firework frame interval to 50 ms and re-enable EEPROM load in setup.\n\nModel used: GPT-5
